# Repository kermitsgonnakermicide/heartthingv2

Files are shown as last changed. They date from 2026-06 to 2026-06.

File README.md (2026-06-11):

# Holtex
<p align="center">

works sometimes :shrug: github sux
>A tiny, wearable ECG monitor!
</p>

# what even is this?
Holtex is an nRF54L15 based holter monitor paired with a MAX30003, a biopotential AFE. It is designed modularly - wherein the MCU module(which just has a xiao nRF54L15 + a MAX17048 i2c fuel gauge) and the ECG module are on completely seperate boards and are joined together by a castellated header.<br>

the ECG and the MCU communicate over SPI(which, in my opinion is far superior to communicating over simple analog) which opens up a whole new realm of possibilities(and complexities).<br>

the device is tiny, just taking up 6x3 cm(can go FAR smaller) and is connected to the body via this awesome [electrode belt](https://store.upsidedownlabs.tech/product/heart-bioamp-band/)<br>

in terms of battery - i'm just using the cheapest thing on hand and it should(in theory) last at least a day, thanks to [ttf's super optimized firmware](https://github.com/TTF-fog/ArrythmiX)<br>

# why??
i ~~was sold into slavery by a chinese warlord and then ttf forced me to make this~~ requested by my good friend [ttf](https://github.com/TTF-fog) to help him redesign the PCB for their project + test out/evaluate the nRF54 as a viable option - this is also why i'm using their firmware available [here](https://github.com/TTF-fog/ArrythmiX).<br>
i'll be answering some frequently asked questions below<br>
**Q - why xiao?**<br>
because they're tiny and epic, and also because I couldnt figure out how to route antennas and no nRF54 modules were very well documented so i left them <br>
**Q- why max30003???**<br>
only because SPI - also because of bad experiences with the ad8232 <br>

# how can YOU assemble this?
1 - use the BOMs, CPLs and gerbers given to print out all of these PCBs and get them both assembled(you can hold on the xiao and solder it yourself)

2 - print both parts of the case(i'm going to try TPU and see how it goes)

3 - place the PCBs in the case and screw the top to the bottom of the case 

4 - feed the electrode belt through the clips 

5 - place the electrode belt right in the center of your torso

6 - connect via Rerun and visualize data!!

# images
<details>
<summary>PCB images</summary>

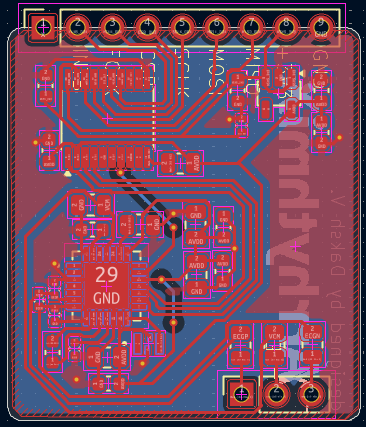
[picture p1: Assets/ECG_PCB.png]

>ECG PCB

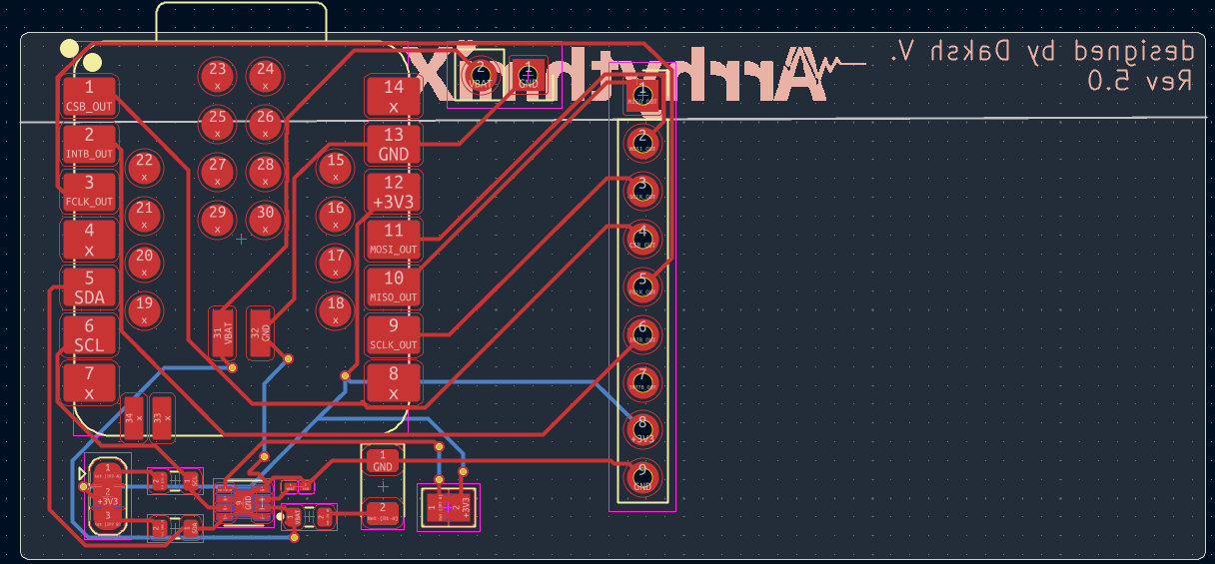
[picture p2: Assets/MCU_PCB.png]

>MCU PCB

</details>

<details>
<summary>Schematic images</summary>

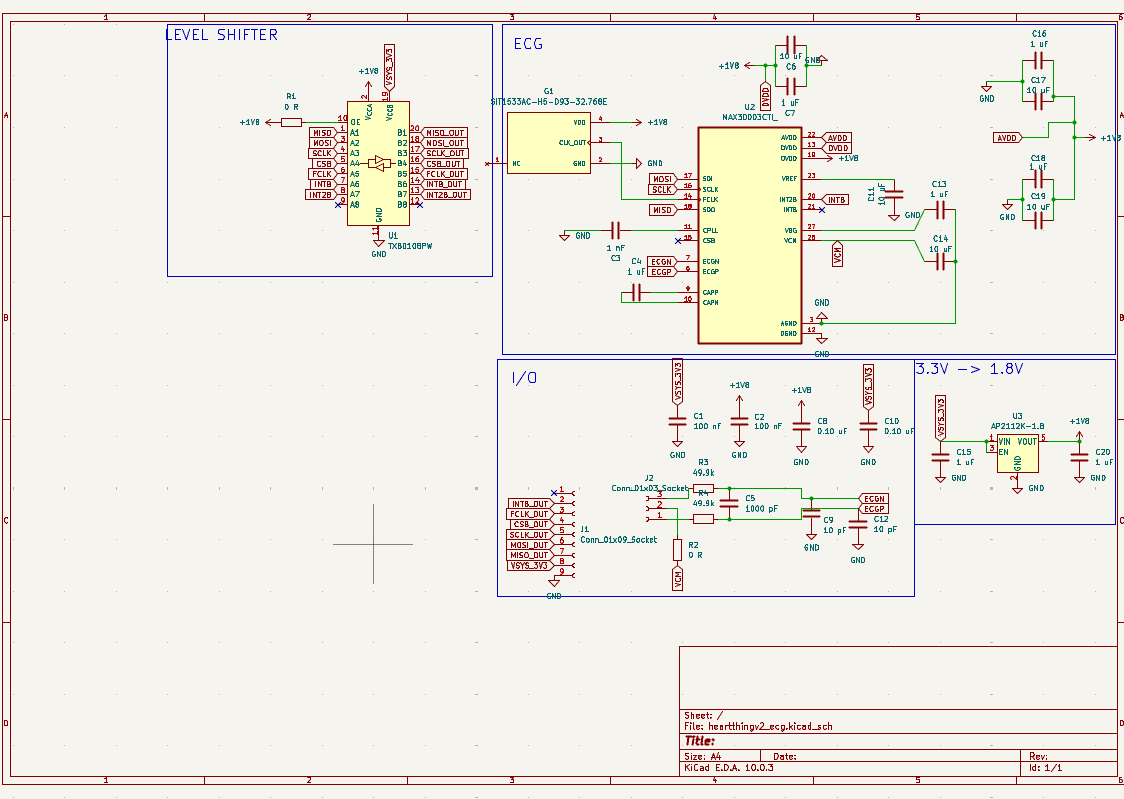
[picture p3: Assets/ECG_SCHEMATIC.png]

>ECG Schematic

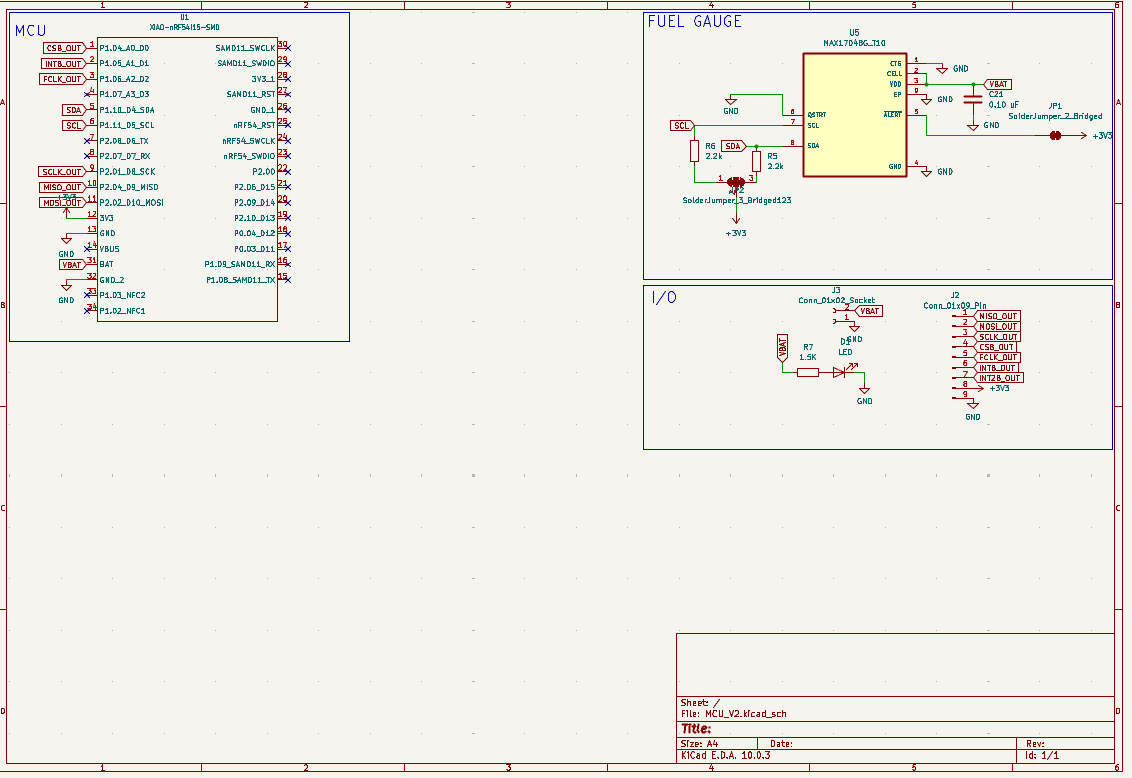
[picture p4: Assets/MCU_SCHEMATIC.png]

>MCU Schematic

</details>

<details>
<summary>3D images</summary>

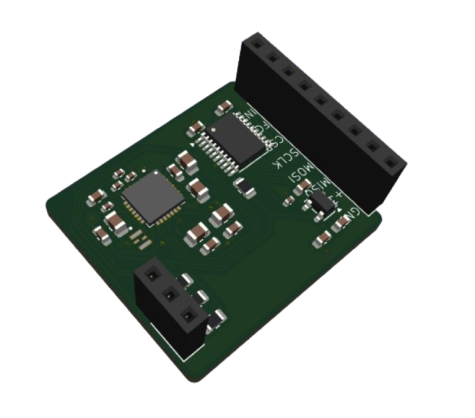
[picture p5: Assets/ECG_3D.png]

>ECG 3D image

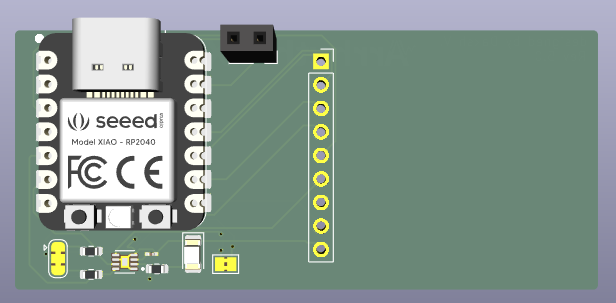
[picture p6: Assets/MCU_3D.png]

>MCU 3D image

</details>

<details>
<summary>CAD/Renders</summary>

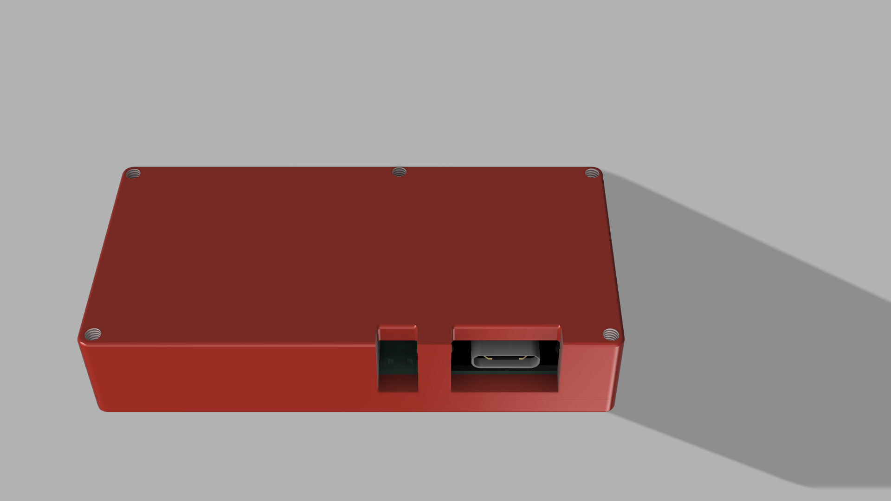
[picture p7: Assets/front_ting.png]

>whole thing with case from the front

PCB
>fun animation!!

</details>

# Zine

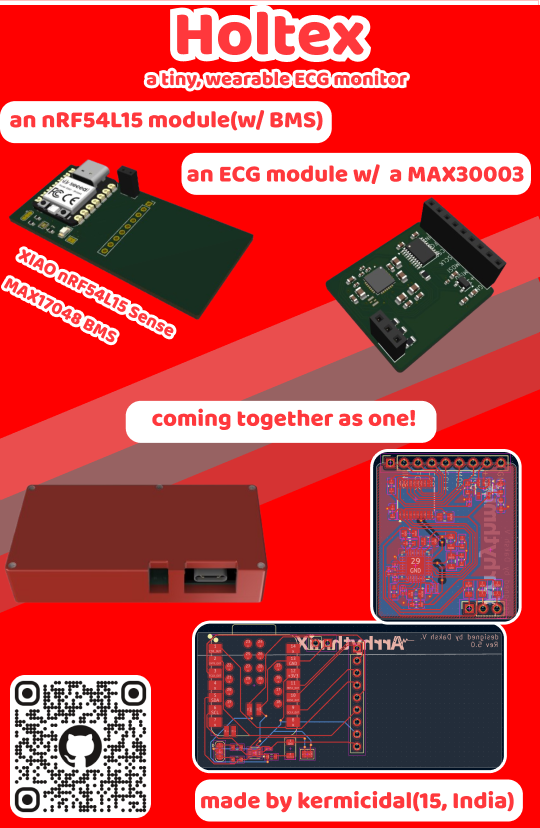
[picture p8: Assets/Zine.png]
Zine


# BOM
Name | Link | QTY | Unit Price | Total Price | Running Total | Notes
--- | --- | ---: | ---: | ---: | ---: | ---
500 mAh LiPo battery | https://robu.in/product/500mah-pcm-protected-micro-li-po-battery/ | 1 | 2.73 | 2.73 | 2.73 |
MCU PCB | Seeed Fusion | 1 | 73.00 | 73.00 | 75.73 | refer to PCB BOM
ECG PCB | JLCPCB | 1 | 57.00 | 57.00 | 132.73 | refer to PCB BOM
M2.5 Screws (10 mm) | https://onlyscrews.in/products/m2-5-x-10mm-hex-allen-socket-head-high-tensile12-9-black-oxide-screw-dia-2-5mm-length-10mm | 15 | 0.07 | 1.05 | 133.78 |
| | | | |  |
TOTAL | | | | 133.78 | |

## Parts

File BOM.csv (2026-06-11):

Name | Link | QTY | Unit Price | Total Price | Notes
500 mAh LiPo Battery | https://robu.in/product/500mah-pcm-protected-micro-li-po-battery/ | 1 | 2.73 | 2.73
MCU PCB | Seeed Fusion | 1 | 73.00 | 73.00 | Refer to PCB BOM
ECG PCB | JLCPCB | 1 | 57.00 | 57.00 | Refer to PCB BOM
M2.5 Screws (M2.5 x 10 mm) | https://onlyscrews.in/products/m2-5-x-10mm-hex-allen-socket-head-high-tensile12-9-black-oxide-screw-dia-2-5mm-length-10mm | 15 | 0.07 | 1.05
TOTAL |  |  |  | 133.78

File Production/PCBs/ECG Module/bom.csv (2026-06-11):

JLCPCB BOM Tool - BOM Matching
BOM name：bom-JLCPCB Assembly Order.xlsx |  |  | Download Time：2026-06-10 15:53:00 |  |  |  | * Our matching results are updated in real-time, but stock and prices may change. If it's been over 24 hours, please re-match before placing your order.
PCB Assembled Qty：5 |  |  | Est. Total Price：46.9328
Your BOM |  |  |  |  | Matched Parts |  |  |  |  |  |  | Order Information
Top Designator | Bottom Designator | Comment | Footprint | JLCPCB Part # | Matches | Part # | Manufacturer | Footprint | Description | Category | Warning | JLCPCB Part # | Product link | Lib Type | Qty | Source | Total Price ($)
C1,C2 |  | 100nF | 0603 |  | Unconfirmed | CC0603KRX7R9BB104 | YAGEO | 0603 | 100nF 50V X7R ±10% 0603 Multilayer Ceramic Capacitors MLCC - SMD/SMT ROHS | Multilayer Ceramic Capacitors MLCC - SMD/SMT | 1.Multiple lines in the BOM have been matched to the same part. Please check if the matching is correct. ; | C14663 | https://jlcpcb.com/partdetail/YAGEO-CC0603KRX7R9BB104/C14663 | Basic | 20 | 20 JLCPCB | 0.212
C8 |  | 0.10uF | 0603 |  | Unconfirmed
C3 |  | 1nF | 0402 |  | Unconfirmed | 0402B102K500NT | FH (Guangdong Fenghua Advanced Tech) | 0402 | 1nF 50V X7R ±10% 0402 Multilayer Ceramic Capacitors MLCC - SMD/SMT ROHS | Multilayer Ceramic Capacitors MLCC - SMD/SMT | 1.Multiple lines in the BOM have been matched to the same part. Please check if the matching is correct. ; | C1523 | https://jlcpcb.com/partdetail/1875-0402B102K500NT/C1523 | Basic | 20 | 20 JLCPCB | 0.036
C5 |  | 1000pF | 0402 |  | Unconfirmed
C10 |  | 0.10uF | 0402 |  | Unconfirmed | CL05B104KO5NNNC | Samsung Electro-Mechanics | 0402 | 100nF 16V X7R ±10% 0402 Multilayer Ceramic Capacitors MLCC - SMD/SMT ROHS | Multilayer Ceramic Capacitors MLCC - SMD/SMT | 1.The comment (CL05B104KO5NNNC) of this part does not match the one (0.10uF) provided in your BOM. Please confirm; | C1525 | https://jlcpcb.com/partdetail/1877-CL05B104KO5NNNC/C1525 | Basic | 20 | 20 JLCPCB | 0.042
C11,C14,C17,C19,C6 |  | 10uF | 0805 |  | Select by System | GRM21BR61H106KE43L | Murata Electronics | 0805 | 10uF 50V X5R ±10% 0805 Multilayer Ceramic Capacitors MLCC - SMD/SMT ROHS | Multilayer Ceramic Capacitors MLCC - SMD/SMT |  | C440198 | https://jlcpcb.com/partdetail/439567-GRM21BR61H106KE43L/C440198 | Basic | 10 | 10 JLCPCB | 1.523
C12,C9 |  | 10pF | 0402 |  | Select by System | CL05C100JB5NNNC | Samsung Electro-Mechanics | 0402 | 10pF 50V C0G ±5% 0402 Multilayer Ceramic Capacitors MLCC - SMD/SMT ROHS | Multilayer Ceramic Capacitors MLCC - SMD/SMT |  | C32949 | https://jlcpcb.com/partdetail/33914-CL05C100JB5NNNC/C32949 | Basic | 20 | 20 JLCPCB | 0.104
C13,C15,C16,C18,C20,C4,C7 |  | 1uF | 0603 |  | Select by System | CL10A105KB8NNNC | Samsung Electro-Mechanics | 0603 | 1uF 50V X5R ±10% 0603 Multilayer Ceramic Capacitors MLCC - SMD/SMT ROHS | Multilayer Ceramic Capacitors MLCC - SMD/SMT |  | C15849 | https://jlcpcb.com/partdetail/16531-CL10A105KB8NNNC/C15849 | Basic | 24 | 24 JLCPCB | 0.2592
R1,R2 |  | 0R | 0805 |  | Unconfirmed | 0805W8F0000T5E | UNI-ROYAL(Uniroyal Elec) | 0805 | -55℃~+155℃ 0Ω 125mW 150V Thick Film Resistor ±1% ±800ppm/℃ 0805 Chip Resistor - Surface Mount ROHS | Chip Resistor - Surface Mount | 1.The comment (0805W8F0000T5E) of this part does not match the one (0R) provided in your BOM. Please confirm; | C17477 | https://jlcpcb.com/partdetail/18165-0805W8F0000T5E/C17477 | Basic | 20 | 20 JLCPCB | 0.044
R3,R4 |  | 49.9k | 0805 |  | Unconfirmed | 0805W8F4992T5E | UNI-ROYAL(Uniroyal Elec) | 0805 | -55℃~+155℃ 125mW 150V 49.9kΩ Thick Film Resistor ±1% ±100ppm/℃ 0805 Chip Resistor - Surface Mount ROHS | Chip Resistor - Surface Mount | 1.The comment (0805W8F4992T5E) of this part does not match the one (49.9k) provided in your BOM. Please confirm; | C17719 | https://jlcpcb.com/partdetail/18407-0805W8F4992T5E/C17719 | Extended | 20 | 20 JLCPCB | 0.046
U1 |  | TXB0108PW | TSSOP-20_4.4x6.5mm_P0.65mm |  | Select by System | TXB0108PWR | Texas Instruments | TSSOP-20 | -40℃~+85℃ 1 1.2V~3.6V 1.65V~5.5V 100Mbps 8 Auto Direction Detection Bidirectional Tri-State TSSOP-20 Translators, Level Shifters ROHS | Translators, Level Shifters |  | C53406 | https://jlcpcb.com/partdetail/TexasInstruments-TXB0108PWR/C53406 | Extended | 2 | 2 JLCPCB | 0.8658
U2 |  | MAX30003CTI_ | QFN50P500X500X80-29N |  | Unconfirmed | MAX30003CTI+ | Analog Devices Inc./Maxim Integrated | QFN-28-EP(5x5) | 0.51uA 0℃~+70℃ 1.1V~2V 10ppm/℃ 18 1V 32.768kHz、12MHz 512Hz 512Hz 96.5dB SPI QFN-28-EP(5x5) Analog Front End (AFE) ROHS | Analog Front End (AFE) | 1.The comment (MAX30003CTI+) of this part does not match the one (MAX30003CTI_) provided in your BOM. Please confirm; | C1519515 | https://jlcpcb.com/partdetail/1610313-MAX30003CTI/C1519515 | Extended | 2 | 2 JLCPCB | 18.0158
U3 |  | AP2112K-1.8 | SOT-23-5 |  | Select by System | AP2112K-1.8TRG1(MS) | MSKSEMI | SOT-23-5 | -40℃~+85℃@(Ta) 1 1.8V 2uA 40uVrms 570mV@(600mA) 600mA 6V 75dB@(1kHz) Fixed Over Current Protection、Over Temperature Protection、Enable Positive SOT-23-5 Voltage Regulators - Linear, Low Drop Out (LDO) Regulators ROHS | Voltage Regulators - Linear, Low Drop Out (LDO) Regulators |  | C22365428 | https://jlcpcb.com/partdetail/MSKSEMI-AP2112K_1_8TRG1_MS/C22365428 | Extended | 5 | 5 JLCPCB | 0.537
G1 |  | SIT1533AC-H5-D93-32.768E | OSC_SIT1533AC-H5-D93-32.768E |  | Select by System | SIT1533AC-H5-D93-32.768E | SiTime | SMD2012-4P | SMD2012-4P Programmable Oscillators ROHS | Programmable Oscillators |  | C17532552 | https://jlcpcb.com/partdetail/SiTime-SIT1533AC_H5_D93_32768E/C17532552 | Extended | 2 | 0 JLCPCB | 0
J1 |  | DNP | PinSocket_1x09_P2.54mm_Vertical
J2 |  | DNP | PinSocket_1x03_P2.54mm_Vertical

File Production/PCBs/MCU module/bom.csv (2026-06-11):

Designator | Footprint | Quantity | Value | LCSC Part #
C21 | 0201 | 1 | 0.10 uF | C284966
D1 | 1206 | 1 | LED | C3646938
J2 | PinSocket_1x09_P2.54mm_Vertical | 1 | Conn_01x09_Pin
J3 | PinSocket_1x02_P2.54mm_Vertical | 1 | Conn_01x02_Socket
R5, R6 | 0603 | 2 | 2.2k | C4190
R7 | 0603 | 1 | 1.5K | C4190
U1 | XIAO-nRF54l15-SMD | 1 | XIAO-nRF54l15-SMD | 101991422
U5 | SON50P200X200X80-9N | 1 | MAX17048G_T10 | C2682616

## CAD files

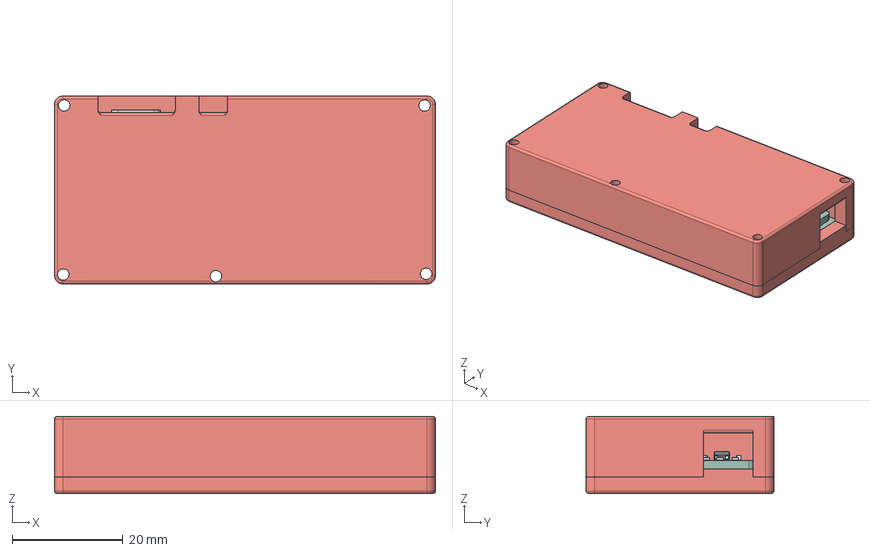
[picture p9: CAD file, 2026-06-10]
CAD/full thing.step
69.0 x 34.0 x 14.0 mm
C_0603_1608Metric_10 x 10
C_0402_1005Metric_5 x 5
R_0805_2012Metric_4 x 4
T2855+8
SOT-23-5_1
C_0805_2012Metric_5 x 5
TSSOP-20_4.4x6.5mm_P0.65mm_1
heartthingv2_ecg_PCB
C_0201_0603Metric_1
LED_1206_3216Metric_1
R_0603_1608Metric_1 x 3
type-c v2
smd_button v3
DOUT
DIN
VSS
VDD
smd_button v3(Mirror)
MCU_V2_PCB
top_case
bottom_case

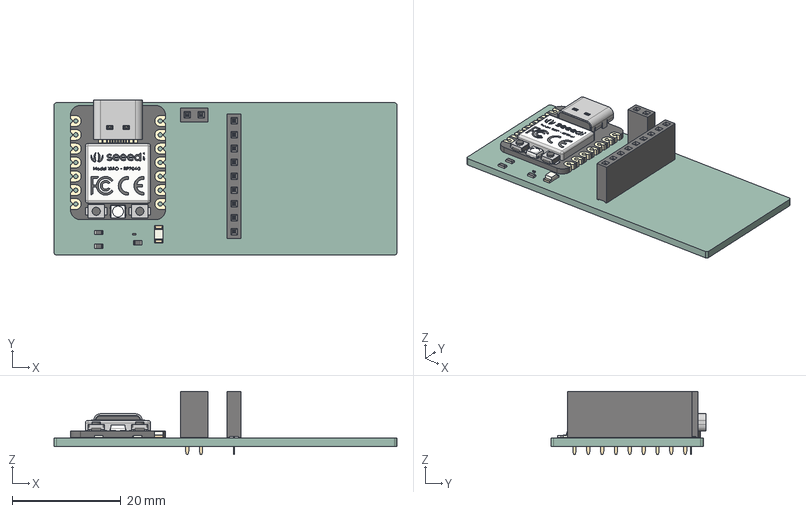
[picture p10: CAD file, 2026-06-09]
PCB/MCU Module/main_board.step
63.0 x 28.5 x 11.6 mm
LED_1206_3216Metric
R_0603_1608Metric x 3
PinSocket_1x02_P2.54mm_Vertical
type-c v2
smd_button v3
DOUT
DIN
VSS
VDD
smd_button v3(Mirror)
PinSocket_1x09_P2.54mm_Vertical
C_0201_0603Metric
MCU_V2_PCB

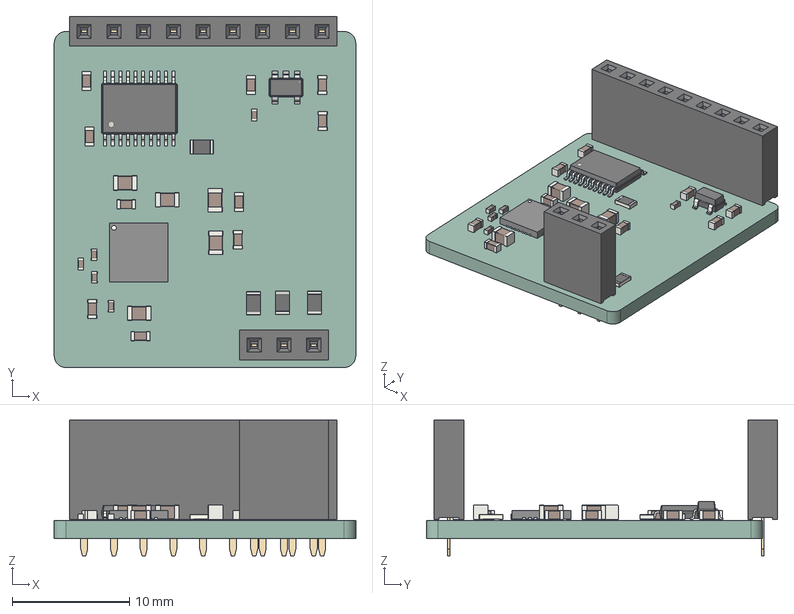
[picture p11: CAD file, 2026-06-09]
PCB/ECG Module/module.step
25.8 x 30.0 x 11.6 mm
C_0603_1608Metric x 10
C_0402_1005Metric x 5
R_0805_2012Metric x 4
T2855+8
SOT-23-5
C_0805_2012Metric x 5
PinSocket_1x03_P2.54mm_Vertical
TSSOP-20_4.4x6.5mm_P0.65mm
PinSocket_1x09_P2.54mm_Vertical
heartthingv2_ecg_PCB

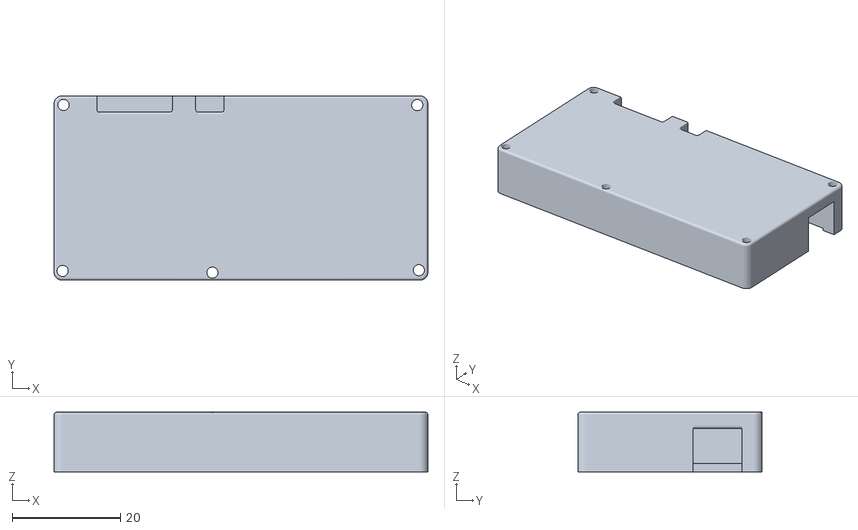
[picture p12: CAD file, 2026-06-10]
Production/3D Prints/top_part.stl
69.0 x 34.0 x 11.0

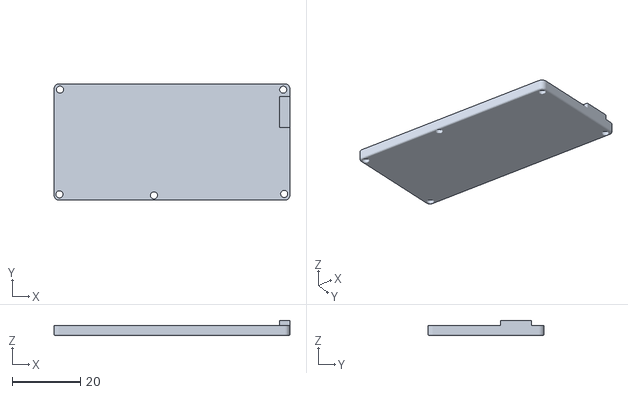
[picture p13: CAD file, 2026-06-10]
Production/3D Prints/bottom_part.stl
69.0 x 34.0 x 4.50

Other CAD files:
CAD/main_board.f3z

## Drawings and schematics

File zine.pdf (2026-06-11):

# Holtex

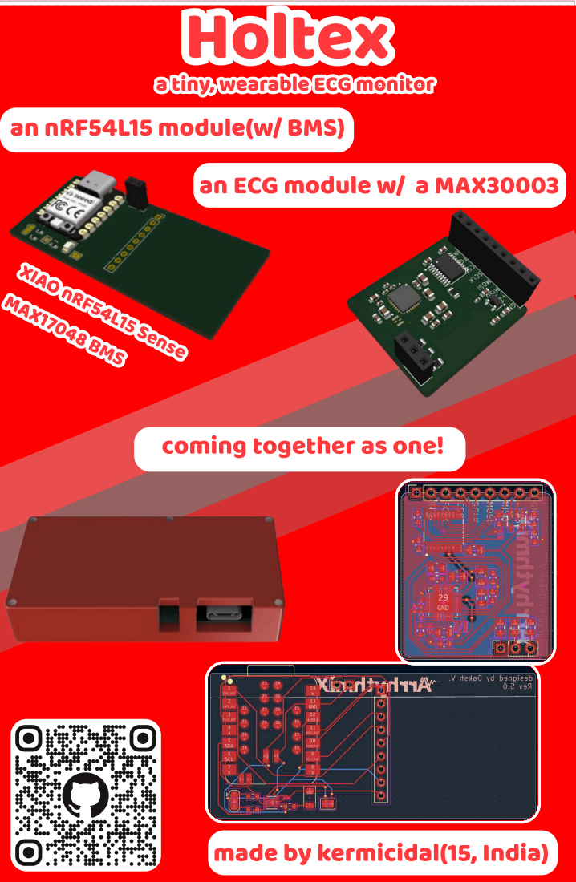
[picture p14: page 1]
XIAO nRF54L15 Sense; MAX17048 BMS

a tiny, wearable ECG monitor

an nRF54L15 module(w/ BMS)

an ECG module w/ a MAX30003

coming together as one!

made by kermicidal(15, India)

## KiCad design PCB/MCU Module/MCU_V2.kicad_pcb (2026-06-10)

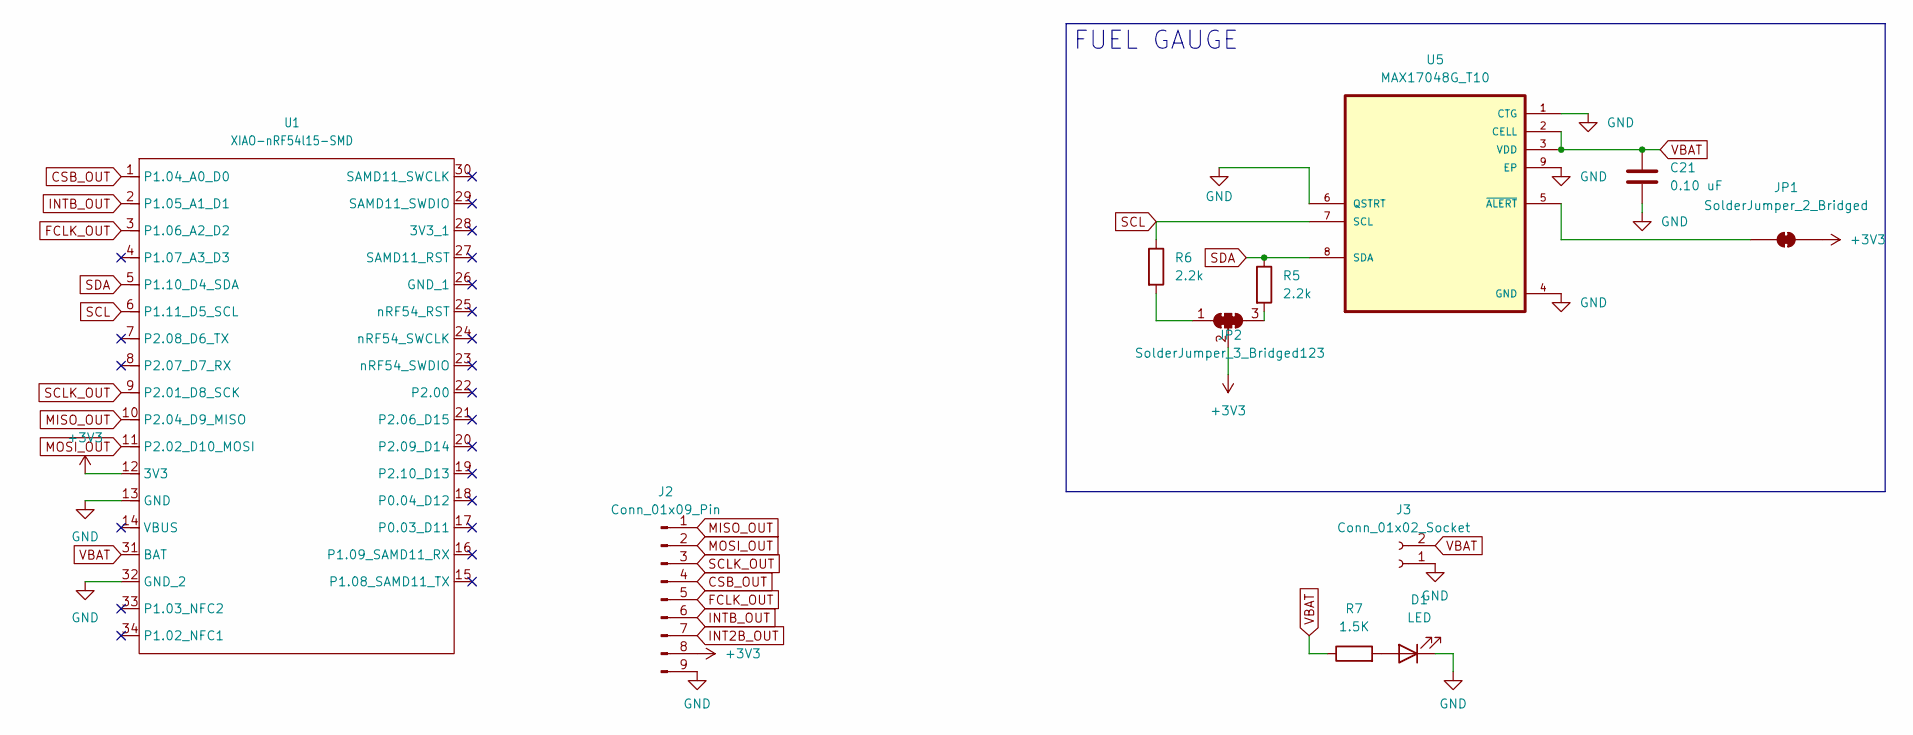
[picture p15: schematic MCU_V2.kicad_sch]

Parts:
C21: 0.10 uF; C_0201_0603Metric_Pad0.64x0.40mm_HandSolder
D1: LED; LED_1206_3216Metric
J2: Conn_01x09_Pin; PinSocket_1x09_P2.54mm_Vertical
J3: Conn_01x02_Socket; PinSocket_1x02_P2.54mm_Vertical
JP1: SolderJumper_2_Bridged; SolderJumper-2_P1.3mm_Bridged2Bar_Pad1.0x1.5mm
JP2: SolderJumper_3_Bridged123; SolderJumper-3_P1.3mm_Bridged123_RoundedPad1.0x1.5mm
R5, R6: 2.2k; R_0603_1608Metric
R7: 1.5K; R_0603_1608Metric
U1: XIAO-nRF54l15-SMD
U5: MAX17048G_T10; SON50P200X200X80-9N

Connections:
+3V3: J2.8, JP1.2 (B), JP2.2 (C), U1.12 (3V3)
CSB_OUT: J2.4, U1.1 (P1.04_A0_D0)
FCLK_OUT: J2.5, U1.3 (P1.06_A2_D2)
GND: C21.2, D1.1 (K), J2.9, J3.1, U1.13 (GND), U1.32 (GND_2), U5.1 (CTG), U5.4 (GND), U5.6 (QSTRT), U5.9 (EP)
INT2B_OUT: J2.7
INTB_OUT: J2.6, U1.2 (P1.05_A1_D1)
MISO_OUT: J2.1, U1.10 (P2.04_D9_MISO)
MOSI_OUT: J2.2, U1.11 (P2.02_D10_MOSI)
unnamed: D1.2 (A), R7.2
unnamed: JP1.1 (A), U5.5 (~ALERT)
unnamed: JP2.1 (A), R6.2
unnamed: JP2.3 (B), R5.2
SCL: R6.1, U1.6 (P1.11_D5_SCL), U5.7 (SCL)
SCLK_OUT: J2.3, U1.9 (P2.01_D8_SCK)
SDA: R5.1, U1.5 (P1.10_D4_SDA), U5.8 (SDA)
VBAT: C21.1, J3.2, R7.1, U1.31 (BAT), U5.2 (CELL), U5.3 (VDD)

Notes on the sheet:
FUEL GAUGE

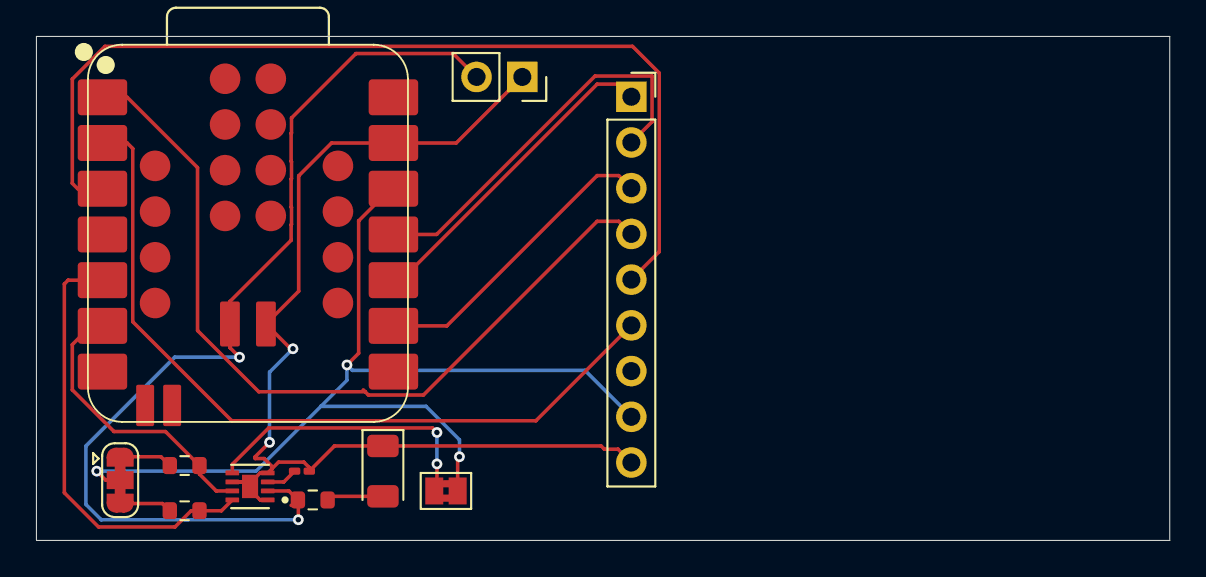
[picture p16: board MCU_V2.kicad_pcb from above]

Board: 2 copper layers, 63.0 x 28.0 mm, 11 parts (0 on the bottom side), 15 nets.

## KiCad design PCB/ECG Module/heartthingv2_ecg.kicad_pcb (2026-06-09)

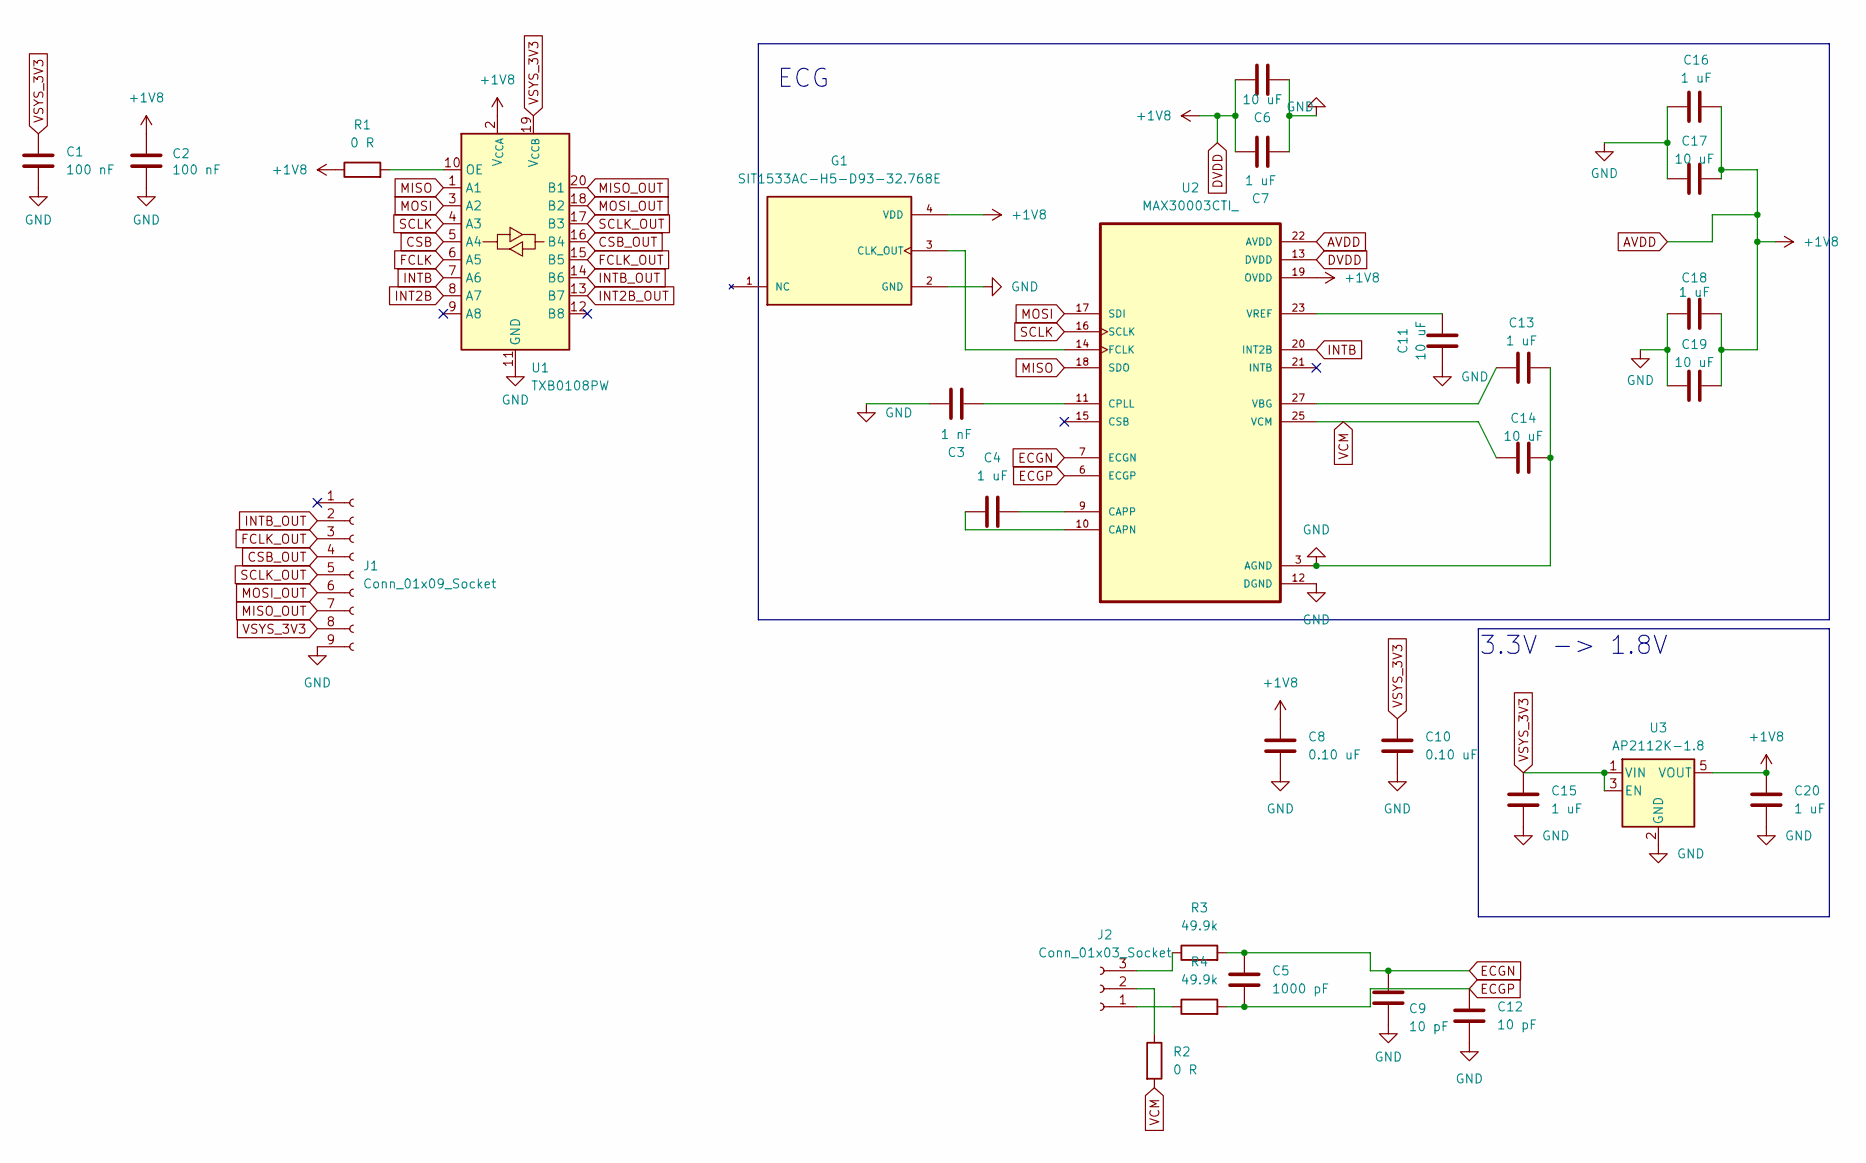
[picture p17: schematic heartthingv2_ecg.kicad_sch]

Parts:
C1, C2: 100 nF; C_0603_1608Metric
C3: 1 nF; C_0402_1005Metric
C4, C7, C13, C15, C16, C18, C20: 1 uF; C_0603_1608Metric
C5: 1000 pF; C_0402_1005Metric
C6, C11, C14, C17, C19: 10 uF; C_0805_2012Metric
C8: 0.10 uF; C_0603_1608Metric
C9, C12: 10 pF; C_0402_1005Metric
C10: 0.10 uF; C_0402_1005Metric
G1: SIT1533AC-H5-D93-32.768E; OSC_SIT1533AC-H5-D93-32.768E; PARTREV 1.4
J1: Conn_01x09_Socket; PinSocket_1x09_P2.54mm_Vertical
J2: Conn_01x03_Socket; PinSocket_1x03_P2.54mm_Vertical
R1, R2: 0 R; R_0805_2012Metric
R3, R4: 49.9k; R_0805_2012Metric
U1: TXB0108PW; TSSOP-20_4.4x6.5mm_P0.65mm
U2: MAX30003CTI_; QFN50P500X500X80-29N
U3: AP2112K-1.8; SOT-23-5

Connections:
AVDD: C2.1, C6.2, C7.2, C8.1, C16.2, C17.2, C18.2, C19.2, C20.1, G1.4 (VDD), R1.1, U1.2 (V_{CCA}), U2.13 (DVDD), U2.19 (OVDD), U2.22 (AVDD), U3.5 (VOUT)
CSB: U1.5 (A4)
CSB_OUT: J1.4, U1.16 (B4)
ECGN: C5.1, C9.1, R3.2, U2.7 (ECGN)
ECGP: C5.2, C12.1, R4.2, U2.6 (ECGP)
FCLK: U1.6 (A5)
FCLK_OUT: J1.3, U1.15 (B5)
GND: C1.2, C2.2, C3.2, C6.1, C7.1, C8.2, C9.2, C10.2, C11.1, C12.2, C13.2, C14.2, C15.2, C16.1, C17.1, C18.1, C19.1, C20.2, G1.2 (GND), J1.9, U1.11 (GND), U2.3 (AGND), U2.8 (AGND), U2.12 (DGND), U2.28 (AGND), U2.29 (AGND), U3.2 (GND)
INT2B: U1.8 (A7)
INT2B_OUT: U1.13 (B7)
INTB: U1.7 (A6), U2.20 (INT2B)
INTB_OUT: J1.2, U1.14 (B6)
MISO: U1.1 (A1), U2.18 (SDO)
MISO_OUT: J1.7, U1.20 (B1)
MOSI: U1.3 (A2), U2.17 (SDI)
MOSI_OUT: J1.6, U1.18 (B2)
unnamed: G1.3 (CLK_OUT), U2.14 (FCLK)
unnamed: J2.1, R4.1
unnamed: J2.2, R2.1
unnamed: J2.3, R3.1
unnamed: R1.2, U1.10 (OE)
unnamed: C4.1, U2.10 (CAPN)
unnamed: C4.2, U2.9 (CAPP)
unnamed: C3.1, U2.11 (CPLL)
unnamed: C13.1, U2.27 (VBG)
unnamed: C11.2, U2.23 (VREF)
SCLK: U1.4 (A3), U2.16 (SCLK)
SCLK_OUT: J1.5, U1.17 (B3)
VCM: C14.1, R2.2, U2.25 (VCM)
VSYS_3V3: C1.1, C10.1, C15.1, J1.8, U1.19 (V_{CCB}), U3.1 (VIN), U3.3 (EN)

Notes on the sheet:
3.3V -> 1.8V
ECG

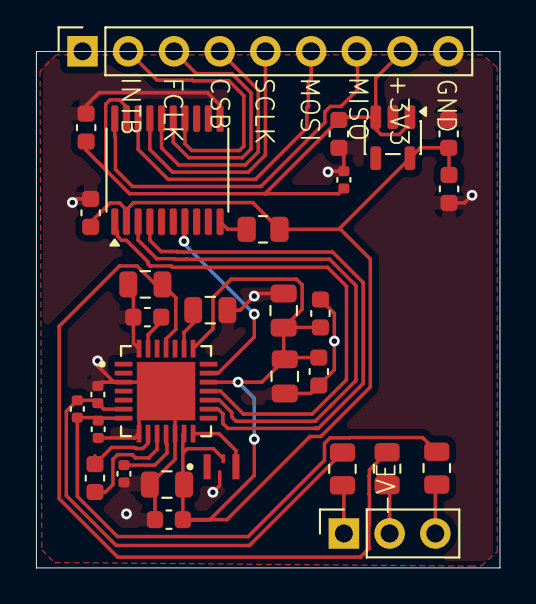
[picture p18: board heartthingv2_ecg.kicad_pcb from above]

Board: 2 copper layers, 25.8 x 28.7 mm, 30 parts (0 on the bottom side), 26 nets.

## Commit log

2026-05-24 no diddy
    [heartthingv2.kicad_sch]
2026-06-09 six seven
    [MCU_V2.kicad_pcb, bom.csv, designators.csv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]
2026-06-09 idk amn
    [ecg_board.step]
2026-06-10 do 3D stuff
    [bottom_part.stl, full thing.step, main_board.f3z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]
2026-06-11 final done ok thankyoubaibai
    [BOM.csv, bom.csv]
2026-06-11 Revise BOM.csv for improved formatting and details
    Updated item names and prices for clarity and consistency.
    [BOM.csv]
